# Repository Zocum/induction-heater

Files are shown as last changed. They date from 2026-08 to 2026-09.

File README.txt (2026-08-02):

# Induction Heater Controller
**STM32 Blue Pill (STM32F103C8T6) — Phase-Locked Resonance Tracking**

> ### ⚠️ Use V3 instead — see `V3/README.md`
>
> **V3 is the recommended version for any new build.** This document describes
> the older single-sketch firmware in `V1/`, kept for reference and for
> existing hardware.
>
> The reason to move is safety, not features. In this version the entire PLL
> runs in `loop()` while TIM1 generates the gate drive in hardware — so if
> `loop()` ever blocks, **the bridge keeps switching unsupervised**: no
> resonance tracking, the run timer never expires, and the PWM enable and lock
> switches stop being polled, so the front panel goes dead while the tank is
> still being driven.
>
> V3 closes that hole with a TIM4 dead-man supervisor that gracefully detunes
> and cuts the gate drive within ~200 ms, an IWDG watchdog behind it, and
> safe-boot arming inhibit after a reset. It also adds external gate-drive
> clamps and an EMI glitch filter on all digital inputs.
>
> V3 needs two hardware provisions this version does not (10 kΩ pull-downs on
> the gate driver inputs, and the GDT clamp transistors on PB8/PB9). The
> migration steps are in `V3/README.md`.
>
> If you stay on this version, at minimum keep the run timer short and never
> leave the heater unattended.

A firmware controller for a ZVS-style induction heater that automatically tracks the resonant frequency of the LC tank circuit using phase-locked loop (PLL) control. Runs on the STM32F103C8T6 ("Blue Pill") board using the Arduino STM32 framework.

---

## Features

- **Automatic resonance tracking** via a proportional phase-locked loop
- **Complementary gate drive** — TIM1 CH1/CH1N pair with hardware dead time (BDTR DTG)
- **Scheduled dead time** — floors at the shoot-through minimum at resonance, ramps up as you operate above it
- **Hardware input capture** — zero-software-latency phase measurement using TIM2 slaved to TIM1
- **Phase-target compensation** — dead time and signal-path delay are converted to degrees at the live frequency, so one `TARGET_PHASE` holds across coil swaps
- **Noise rejection** — ignores zero-crossing edges near PWM reload and compare events
- **Graceful exits** — soft stop, timer expiry and manual unlock all detune off resonance first, then cut the gates
- **PWM enable switch** — gate drive stays off at power-up until deliberately armed
- **Run timer on a pot** — 0-5 min, followed live, adjustable mid-run
- **Relay output** tied to the PWM state
- **DS18B20 temperature sensing** — raw 1-Wire bit-bang, no library dependency
- **SH1106 128x64 OLED display** — live frequency, phase, temperature, error, uptime, timer, and lock status
- **I2C bus guard** — health check, frame skip and bus recovery so a wedged display cannot stall the control loop
- **Physical controls** — lock switch, frequency UP/DOWN buttons with hold-to-repeat acceleration
- **Flash-optimised** — direct TIM1/TIM2 register access, no HardwareTimer abstraction

---

## Hardware

### Microcontroller
- STM32F103C8T6 ("Blue Pill"), 72 MHz

### Pin Map

| Pin | Function |
|-----|---|
| PA8 | PWM output -> gate driver (TIM1 CH1) |
| PB13 | Complementary PWM output -> gate driver (TIM1 CH1N) |
| PA0 | Tank current zero-crossing via LM339 (TIM2 CH1 input capture) |
| PA1 | DS18B20 temperature sensor (1-Wire) |
| PA2 | Run-timer setpoint pot wiper (analog) |
| PB0 | Relay driver (follows PWM state) |
| PB1 | PWM enable switch (active HIGH) |
| PB6 | I2C1 SCL -> OLED |
| PB7 | I2C1 SDA -> OLED |
| PB12 | Lock switch (active HIGH) |
| PB14 | Frequency UP button (active HIGH) |
| PB15 | Frequency DOWN button (active HIGH) |

> **PB12 conflict:** PB12 is also TIM1_BKIN. If you wire a hardware overcurrent
> trip into the break input, move the lock switch to a free pin (PB5/PB8/PB9) first.

### Additional Components
- **LM339 comparator** on CT output for clean zero-crossing detection
- **4.7 kOhm pull-up** resistor on PA1 to 3.3 V (DS18B20)
- **SH1106 128x64 OLED** on I2C address (default)
- Current transformer on tank circuit, burden resistor to GND
- **Two GDTs**, primaries driven differentially from the CH1/CH1N pair. The second is wired reversed so leg B runs 180 degrees anti-phase off the same pair and inherits the same dead band — one pair protects both half-bridges.
- **Relay module** on PB0. Set `RELAY_ACTIVE_LOW` to match: 1 for a typical opto-isolated board (LOW = energized), 0 for a low-side transistor driver.
- **Potentiometer** to 3.3 V / GND, wiper to PA2

---

## Dependencies

| Library | Purpose |
|---|---|
| `Wire` | I2C for OLED |
| `U8x8lib` (`U8g2`) | OLED driver (SH1106, HW I2C) |

No OneWire or DallasTemperature library required — DS18B20 is bit-banged manually.

---

## How It Works

### Frequency Generation
TIM1 is configured in PWM mode directly via registers, running at 72 MHz with no prescaler. The output frequency is:

```
f = 72,000,000 / (ARR + 1)
```

CCR1 is always set to half of ARR+1, giving a 50% duty cycle. Frequency is updated live by writing new ARR/CCR1 values under a brief interrupt lock.

Output is a **complementary pair** — CH1 (PA8) and CH1N (PB13) — with dead time inserted in hardware by the BDTR DTG field. During the dead-time window both pins go LOW, the GDT primary sits at 0 V, and that leg's gates are off.

### Dead Time
Dead time is scheduled rather than fixed. It floors at `DT_FLOOR_NS` (800 ns) at resonance and under lock, and ramps toward `DT_MAX_NS` (1500 ns) at `DT_SLOPE_NS_PER_KHZ` (100 ns/kHz) as the drive moves above resonance, slew-limited to `DT_SLEW_NS` (40 ns) per scheduler tick. The floor is the **shoot-through minimum and is never crossed**.

The default 800 ns floor is derived for an FF200R12KS4 at Tvj = 125 C, 200 A, +/-15 V, Rg = 4.7 ohm: td(off) + tf - td(on) = 480 ns delay race, plus tail current and GDT/driver skew and margin. **Verify on your own hardware** — scope gate-off until collector current (tail included) reaches zero, hot, at your actual Rg.

Set `DT_SCHEDULE_ENABLE` to 0 for a fixed `DT_FLOOR_NS` with no schedule.

### Phase Measurement (Hardware Input Capture)
Phase is measured entirely in hardware with zero software latency:

- **TIM1** generates the PWM on PA8 and emits an Update trigger (TRGO) on each reload (every PWM rising edge).
- **TIM2** runs at 72 MHz, slaved to TIM1 via ITR0 in Reset Mode — `TIM2->CNT` is reset to 0 at every PWM rising edge.
- **TIM2 CH1** (PA0) is configured as input capture, rising edge. `TIM2->CCR1` is latched in hardware the instant PA0 goes high.

The captured value directly encodes the phase offset:

```
phase (degrees) = (TIM2->CCR1 / (TIM1->ARR + 1)) x 360
```

Software/ISR latency is effectively zero. The residual delays are the LM339 comparator propagation delay plus CT conditioning (together `SIG_DELAY_NS`, default 1560 ns) and the gate dead time, which offsets the real CH1 edge from the TRGO reference the phase is measured against. The CC1IF flag is polled in the main loop at ~200 Hz rather than using interrupts.

### Phase Target Compensation
Both residual delays are **fixed-time**, so their contribution in degrees grows with frequency. The firmware converts them at the live frequency and references them to the point at which `TARGET_PHASE` was tuned:

```
phase_target_eff = TARGET_PHASE
                 + dtPhaseDeg(dead_time_ns + SIG_DELAY_NS, cur_freq)
                 - dtPhaseDeg(DT_TUNE_NS   + SIG_DELAY_NS, F_TUNE_HZ)
```

This is what lets a single `TARGET_PHASE` hold the same *actual* tank phase across coil swaps and load pull, and keeps the lock point from drifting as the dead-time schedule moves. `DT_TUNE_NS` (800 ns) and `F_TUNE_HZ` (40500 Hz) must describe the conditions you tuned `TARGET_PHASE` under.

### PLL Control
The control loop runs at ~200 Hz. It is **proportional-only** — frequency is the time-integral of phase, so a single gain on the phase error already drives the steady-state error to zero, with no I or D term needed.

| Constant | Default | Role |
|---|---|---|
| `LOCK_K` | 5.0 | Hz of correction per degree of phase error |
| `MAX_STEP` | 50.0 | Max frequency change per update (Hz) — stops a stray sample yanking the drive |
| `LOCK_DEADBAND` | 2.0 | Degrees; inside this the frequency is held, killing idle dither |
| `FREQ_UPD_INT` | 20 | ms between corrections (captures arrive ~4x faster) |
| `PH_N` | 15 | Depth of the moving-average phase filter |

The phase-vs-frequency slope is steepest near resonance, so the closer `TARGET_PHASE` is tuned toward Fres, the gentler `LOCK_K` has to be — too hot and it limit-cycles around target.

**Acquisition** always begins `ACQ_OFFSET` (12 kHz) **above** the resonance estimate and walks down, so the loop always approaches from the stable, inductive side. Seeding from wherever the knob is parked is what let earlier versions run away. `locked_freq` is only trusted once the loop is genuinely parked inside the deadband.

A filtered phase jump greater than `PHASE_JUMP_TH` (120 degrees) means the drive fell through resonance to the capacitive side. This forces an unlock and a jump back above resonance, reported as `!JUMP` on serial.

### Noise Rejection
Zero-crossing edges arriving within `1/NOISE_DIV` (1/20 = 5%) of either the PWM reload point or the compare event are discarded. If more than `REJECT_SWEEP_TH` (15) consecutive edges are rejected, the frequency is swept upward at 15 Hz/tick to escape the dead zone.

### I2C Bus Guard
Every OLED write is a blocking transfer, and the PLL, the run timer and the switch polling all live in the same `loop()`. A display wedged by an EMI burst would therefore stall the control loop while TIM1 kept the bridge switching. Before each frame the firmware checks both I2C lines are idle-high; if not it skips the frame and, at most every 500 ms, recovers the bus (9 SCL pulses, manual STOP, controller re-init). The `s` command reports `i2crec` / `i2cskip` so a marginal bus is visible before it becomes a failure.

The bus runs at 100 kHz rather than the 400 kHz default for noise margin. See `HARDWARE.md` in the V3 project for the hardware-side hardening checklist.

---

## Frequency Range

| Parameter | Constant | Value |
|---|---|---|
| Minimum frequency | `MIN_FREQ` | 1 kHz |
| Maximum frequency | `MAX_FREQ` | 100 kHz |
| Step size | `FREQ_STEP` | 100 Hz |
| Default start | `start_frequency` | 46 kHz |
| Unlocked offset | `UNLOCK_OFFSET` | +4000 Hz above start |
| Acquisition offset | `ACQ_OFFSET` | +12000 Hz above resonance estimate |
| Unlock / timer backoff | `UNLOCK_BACKOFF` / `TIMER_BACKOFF` | 7000 Hz |
| Soft-stop backoff | `PWM_SOFTSTOP_OFFSET` | 7000 Hz |
| Backoff ramp rate | `FREQ_RAMP_HZ_PER_MS` | 7.0 Hz/ms (~7 kHz in 1 s) |

---

## Controls

Two switches gate the bridge, and both matter:

- **PWM enable (PB1)** — master. PWM does *not* run at power-up; the gate drivers are held at 0 V until this is flipped HIGH. This lets you power the bridge and charge the DC link first, then start switching. Turning it off while locked performs a soft stop: ramp `PWM_SOFTSTOP_OFFSET` up off resonance over ~1 s, *then* cut the gates. Not locked, the gates cut immediately.
- **Lock (PB12)** — engages closed-loop tracking and arms the run timer. With PWM on and lock off, the bridge free-runs at the current manual frequency.

The **pot (PA2)** sets the run time, 0-5 min (`TIMER_MAX_S`, with a `TIMER_MIN_S` = 10 s floor). It is followed live, so the duration can be changed mid-run — turn it up for more time, or down toward zero to end the run now. Below `TIMER_OFF_FRAC` (2%) the timer is disabled and lock runs indefinitely. On expiry the drive parks `TIMER_BACKOFF` above resonance and unlocks, but **PWM stays on and the relay stays energized**; re-lock to run again. Reported as `!TIMER` on serial.

Calibrate the pot ends with `POT_RAW_LO` / `POT_RAW_HI`: read the raw counts at each knob extreme from the `s` command (`pot=`), then set these slightly *inside* the measured values so 0 and full scale are easy to reach.

---

## Display Layout (OLED)

```
Induction Heater
Relay: ON         <- follows PWM state
L: 46.25kHz       <- L = locked, F = free/manual
T:  68C           <- DS18B20 temperature, "--" if absent
P: 23.1 E: 0.3    <- live phase + error (error shown when locked)
Time 03:42        <- uptime
Run -02:15        <- timer: "Run -mm:ss" / "Set mm:ss" / "Timer done" / "Timer off"
** LOCKED **      <- or "Tracking..." / "PWM ON" / "PWM OFF"
```

Row 4 shows the live phase whenever a valid capture exists, regardless of lock state, so you can watch phase change while sweeping manually; the `E:` error field appears only when locked. Row 7 shows `PWM OFF` whenever the enable switch is down, which takes precedence over the lock state.

---

## Calibration

Do this on the bench with the **tank unpowered** and the gate drive scoped. Dead time first — the phase target depends on it.

**1. Dead time.** Scope gate-off until collector current (tail current included) reaches zero, hot, at your actual Rg and Vge(off). Set `DT_FLOOR_NS` to that plus margin, and set `DT_TUNE_NS` to the dead time you are about to tune the phase target at. At startup the schedule is printed to serial:

```
DT floor=800ns max=1500ns tune=800ns DTGfloor=0x3A
```

**2. Phase target.** `TARGET_PHASE` is the measured phase at true resonance — mostly the LM339 propagation delay and CT conditioning, plus the dead-time offset.

1. Enable debug output (`v` via serial).
2. Manually sweep frequency using the UP/DOWN buttons until resonance is found.
3. Note the phase reading at true resonance.
4. Set `TARGET_PHASE` to that value.
5. Set `F_TUNE_HZ` to the frequency you tuned at, and `SIG_DELAY_NS` to your measured signal-path delay. **Measure this one** — the in-code comment describes a 250 ns two-coil fit (42 deg @ 77.5 kHz, 22 deg @ 24.5 kHz) but the constant actually ships at 1560 ns, so the comment and the value disagree.
6. Recompile and flash.

At startup, the target phase is printed to serial:
```
Target phase=-122.0deg
```

Retune after **any** change to the dead time. The `s` command reports both the raw target (`tgt=`) and the compensated one in use (`eff=`).

**3. Pot ends.** Read raw counts at both knob extremes from `s` (`pot=`), then set `POT_RAW_LO` / `POT_RAW_HI` just inside those values.

---

## Serial Commands

| Command | Action |
|---|---|
| `f+` | Increase start frequency by one step |
| `f-` | Decrease start frequency by one step |
| `s` | Status line: frequency, lock, `pwm=`, `pot=`, `set=`, `tgt=`, `eff=`, `dt=`, `i2crec=`, `i2cskip=` |
| `v` | Toggle verbose debug output (phase data every 100 ms) |

The firmware also emits unsolicited `!JUMP` (resonance crossing detected) and `!TIMER` (run timer expired).

---

## Building & Flashing

This project targets the **Arduino STM32** (STM32duino) framework.

1. Install [STM32duino](https://github.com/stm32duino/Arduino_Core_STM32) board package in Arduino IDE.
2. Install **U8g2** library (for `U8x8lib.h`).
3. Select board: **Generic STM32F1 series -> BluePill F103C8**.
4. Upload method: STLink or serial bootloader.
5. Compile and flash.

Builds to roughly 35 KB of flash and 1.8 KB of RAM, comfortably inside the C8's nominal 64 KB.

---

## Safety Notes

> Induction heaters operate at high voltages and currents. The LC tank can develop dangerous voltages even from low supply rails, and the DC link stays charged after power-down. Ensure proper isolation, enclosure, and never operate without adequate knowledge of high-frequency power electronics.

- **This version has no loop supervision.** The PLL runs in `loop()` while TIM1 generates gate drive in hardware, so any blocking fault in `loop()` leaves the bridge switching with the front panel unresponsive. The I2C guard closes the one known cause; it does not make the loop supervised. V3 adds a TIM4 dead-man and an IWDG watchdog — see `V3/README.md`.
- `DT_FLOOR_NS` is a **shoot-through floor**. Verify it against your own devices before applying bus voltage; the default is derived for one specific IGBT.
- The firmware does not implement over-temperature shutdown by itself — the DS18B20 is instrumentation only. Add hardware protection.
- Always verify gate driver signals, including the dead band, with an oscilloscope before connecting the full power stage.
- The PWM enable switch is the master arm and the lock switch enables closed-loop control; ensure the heater is in a safe state before flipping either.
- Add 10 kOhm pull-downs on the gate driver inputs so they read a hard OFF while the MCU pins float during reset.

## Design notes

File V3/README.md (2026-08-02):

# Induction Heater Controller — V3

**STM32 Blue Pill (STM32F103C8T6) — phase-locked resonance tracking for a
full-bridge ZVS induction heater.**

V3 is a ground-up restructure of the single-sketch V1 firmware into a modular
PlatformIO project, built around one change of principle: **the PLL runs in
`loop()`, so `loop()` is a safety-critical path and is now supervised in
hardware.** Everything else follows from that.

> ⚠️ This firmware drives a mains-fed full bridge into a resonant tank. Read
> [Safety](#safety) before powering anything. The `TARGET_PHASE_DEG` and
> `DT_FLOOR_NS` constants **must** be retuned for your hardware — the shipped
> values are for one specific build.

---

## What's new since V1

| | V1 (`uC_logic.ino`) | V3 |
|---|---|---|
| Structure | one 1058-line `.ino` | 6 modules, `src/` + `include/`, central `config.h` |
| Build | Arduino IDE | PlatformIO (`bluepill_f103c8_128k`) |
| Loop freeze | **bridge keeps switching, unsupervised** | TIM4 dead-man → graceful detune → MOE cut → IWDG reset |
| Watchdog | none | IWDG, ~800 ms, with safe-boot arming inhibit |
| Gate drive | TIM1 MOE only | + external GDT input clamps (`GDT_EN`/`GDT_NEN`) |
| Digital inputs | raw `digitalRead()` | `stable_read()` EMI glitch filter on all four |
| I2C failure | blocks `loop()` | health check, frame skip, bounded bus recovery |
| Restart | immediate | `RESTART_LOCKOUT_MS` cooldown for bleeder discharge |

If you are running V1, see [MIGRATING](#migrating-from-v1) — the pin map grew
and V3 needs two new hardware provisions.

---

## Layout

```
platformio.ini      board, framework, U8g2 dependency
include/config.h    ALL tunables — pins, frequencies, gains, safety timings
src/main.cpp        module wiring + UI (buttons, switches, pot, serial)
src/bridge.cpp      TIM1 PWM/dead-time/MOE, TIM2 capture, relay, GDT clamps
src/pll.cpp         acquisition, phase tracker, backoff ramps
src/safety.cpp      TIM4 supervisor + IWDG
src/oled.cpp        SH1106 driver with I2C bus guard
src/ds18b20.cpp     bit-banged 1-Wire (no library)
HARDWARE.md         I2C/EMI hardening checklist + bench validation procedure
```

Tune the machine in `config.h`. You should rarely need to touch anything else.

---

## Hardware

### Pin map

| Pin | Function |
|-----|---|
| PA8 | PWM out → gate driver (TIM1_CH1) |
| PB13 | Complementary PWM out (TIM1_CH1N) |
| PA0 | Tank current zero-crossing from LM339 (TIM2_CH1 capture) |
| PA1 | DS18B20 (4.7 kΩ pull-up to 3.3 V) |
| PA2 | Run-timer setpoint pot wiper (analog) |
| PB0 | Relay driver (follows PWM state) |
| PB1 | PWM enable switch (active HIGH) |
| PB12 | Lock switch (active HIGH) — *also TIM1_BKIN, see note* |
| PB14 / PB15 | Frequency UP / DOWN buttons |
| PB6 / PB7 | I2C1 SCL / SDA → SH1106 OLED |
| **PB8** | **GDT_EN — gate-drive clamp release (new in V3)** |
| **PB9** | **GDT_NEN — inverted clamp enable (new in V3)** |

> **PB12 conflict:** PB12 is TIM1_BKIN. If you ever wire a hardware overcurrent
> trip into the break input, move the lock switch to PB5/PB8/PB9 first.

### Required external provisions

1. **10 kΩ pull-downs on both MIC4421/4422 driver inputs.** During an IWDG
   reset the MCU pins float for a few ms. OSSI drives the outputs low whenever
   the timer is alive, but the reset window itself needs the resistors.
2. **GDT clamp transistors** on `GDT_EN`/`GDT_NEN`, with a 10 k pull-down on EN
   and 10 k pull-up on /EN so the safe (clamped) state holds through reset
   before firmware takes over.

`HARDWARE.md` covers the I2C/EMI hardening — pull-up stiffening, series
resistors, cable twisting — in priority order.

---

## How it works

### Frequency and dead time

TIM1 generates a complementary pair on PA8/PB13 at `f = 72 MHz / (ARR+1)`,
50 % duty, with **hardware dead time** from the BDTR DTG field. Both GDT
primaries are driven differentially; the second is wired reversed, so one pair
protects both half-bridges.

Dead time is *scheduled*, not fixed: it floors at `DT_FLOOR_NS` (800 ns — the
shoot-through minimum, never crossed) at resonance and ramps toward
`DT_MAX_NS` as you operate above resonance, at `DT_SLOPE_NS_PER_KHZ`. The
phase target is compensated for the live dead time and for the fixed
`SIG_DELAY_NS` signal-path delay, so **one** `TARGET_PHASE_DEG` holds the same
actual tank phase across coil swaps and load pull.

### Phase measurement

Zero software latency. TIM1's update event drives TRGO → TIM2 ITR0 in reset
mode, so `TIM2->CNT` clears on every PWM rising edge; TIM2_CH1 latches `CCR1`
the instant PA0 goes high:

```
phase (deg) = (TIM2->CCR1 / (TIM1->ARR + 1)) × 360
```

`CC1IF` is polled at ~200 Hz. Edges landing within `1/NOISE_DIV` of the reload
or compare event are discarded as noise.

### Control

Proportional-only. Frequency is the time-integral of phase, so a single gain
on the phase error already drives steady-state error to zero — no I or D term.
`LOCK_K` sets aggressiveness, `MAX_STEP` caps the per-update jump, and
`LOCK_DEADBAND` silences idle dither.

Acquisition always **starts `ACQ_OFFSET` above** the resonance estimate and
walks down, clearing the unstable near-resonance band. Overshoot the lock point
and the measured angle wraps, and the loop runs away to `MAX_FREQ`.

Every graceful exit — soft stop, timer expiry, manual unlock — uses a
non-blocking ramp at `FREQ_RAMP_HZ_PER_MS` to detune *first*, then cuts the
gates. This preserves ZVS on the way out and avoids ringing the input filter.

---

## Safety

Three layers, in the order they act:

**Layer 1 — TIM4 dead-man, ~200 ms.** `loop()` feeds a heartbeat. If it goes
stale for `SAFETY_STALL_MS` while PWM is enabled, a 1 kHz ISR takes over and
performs the *same* graceful detune as a normal soft stop — ramping up
`SAFETY_RAMP_HZ_TICK` per ms to `PWM_SOFTSTOP_OFFSET` above the stall
frequency, settling, then cutting MOE and latching `SAFETY_FAULT`.

**Layer 2 — IWDG, ~800 ms.** LSI-clocked, survives anything short of power
loss. Fed only from the main loop, with one deliberate exception: the Layer-1
ISR keeps feeding it *while ramping* so a reset can't fire mid-detune. Once MOE
is cut, feeding stops.

**Layer 3 — I2C bus guard.** `oled.cpp` checks both lines are idle-high before
every transaction, skips the frame if not, and attempts bounded bus recovery
(9 clock pulses + manual STOP + re-init). This is what stops a wedged display
from invoking layers 1–2 in the first place.

**After a watchdog reset** the firmware boots into a safe state and *refuses to
arm PWM* until the enable switch has been cycled through OFF. Row 7 shows
`WDT rst-sw off`.

A latched `SAFETY_FAULT` clears only by cycling the PWM switch low.

---

## Building

Needs [PlatformIO](https://platformio.org/). The U8g2 dependency is fetched
automatically.

```bash
pio run              # build
pio run -t upload    # flash via ST-Link
pio device monitor   # 115200 baud
```

Board is `bluepill_f103c8_128k` — the C8 is built as the 128 k CB part because
the firmware overflows the nominal C8 flash size. Serial is USART1
(PA9 TX / PA10 RX); uncomment the CDC block in `platformio.ini` for USB serial.

---

## Operating

Two switches gate the bridge, and both matter:

- **PWM enable (PB1)** — master. PWM does *not* run at power-up. Bring up the
  bus and charge the DC link first, then flip this. Turning it off performs a
  soft stop (detune, then gate cut).
- **Lock (PB12)** — engages closed-loop tracking and arms the run timer. With
  PWM on and lock off, the bridge runs open-loop at the manual frequency.

The **pot (PA2)** sets run time, 0–5 min, followed live. Below
`TIMER_OFF_FRAC` the timer is disabled and lock runs indefinitely. On expiry
the drive parks `TIMER_BACKOFF` above resonance with PWM still on.

### Display

```
Induction Heater
Relay: ON            follows PWM state
L: 43.25kHz          L = locked, F = free/manual
T:  68C              DS18B20, "--" if absent
P: 23.1 E: 0.3       live phase + error (error shown when locked)
Time 03:42           uptime
Run -02:15           timer: Run/Set/Timer done/Timer off
** LOCKED **         safety state dominates this row
```

### Serial commands (115200)

| Cmd | Action |
|---|---|
| `f+` / `f-` | Nudge frequency one `FREQ_STEP` |
| `s` | Status: freq, lock, pwm, gdt, pot, phase target, dead time, safety state, `i2crec`/`i2cskip` |
| `v` | Toggle verbose phase debug (100 ms) |
| `x` | **Deliberately freeze the loop** to validate the safety chain. Refused while PWM is enabled. |

---

## Calibration

Do this on the bench with the **tank unpowered** and the gate drive scoped.

1. **Dead time.** Scope gate-off to collector current (tail included) at your
   actual Rg and Vge(off), hot. Set `DT_FLOOR_NS` to that plus margin. The
   shipped 800 ns is for an FF200R12KS4 at 125 °C, 200 A, ±15 V, Rg = 4.7 Ω.
2. **Phase target.** Enable debug (`v`), sweep manually with the UP/DOWN
   buttons to find resonance, note the phase, and set `TARGET_PHASE_DEG`.
   Set `DT_TUNE_NS` to the dead time you tuned at.
3. **Pot ends.** Read raw counts at both knob extremes via `s` (`pot=`), then
   set `POT_RAW_LO`/`POT_RAW_HI` slightly *inside* those values.
4. **Validate the safety chain** — full procedure in `HARDWARE.md`.

---

## Migrating from V1

1. Add the two hardware provisions above (driver pull-downs, GDT clamps). The
   watchdog is not safe to run without them.
2. Carry your tuned constants across into `config.h`: `TARGET_PHASE_DEG`
   (V1 `TARGET_PHASE`), `DT_FLOOR_NS`, `DT_TUNE_NS`, `SIG_DELAY_NS`,
   `F_TUNE_HZ`, `POT_RAW_LO`/`HI`, `START_FREQUENCY`.
3. Note `ACQ_OFFSET` changed from 12000 to 6000 Hz, and `START_FREQUENCY` from
   46000 to 43000 — check both against your coil.
4. Flash, then run the bench validation in `HARDWARE.md` *before* connecting
   the power stage.

---

## Safety notes

Induction heaters operate at high voltages and currents. The LC tank develops
dangerous voltages even from low supply rails, and the DC link stays charged
after power-down.

- Always verify gate drive on a scope before connecting the power stage.
- The firmware has **no over-temperature shutdown**. The DS18B20 is
  instrumentation only — add hardware thermal protection.
- The supervisor protects against *firmware* stalls. It is not a substitute for
  a hardware overcurrent trip into TIM1_BKIN.
- Never operate without adequate knowledge of high-frequency power electronics.

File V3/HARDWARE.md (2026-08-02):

# OLED / I2C hardware hardening checklist

Goal: cut the rate of corrupted I2C transactions so the firmware's recovery
layer (oled.cpp) almost never has to act. Ordered by payoff.

## At the STM32 end

1. **Stiffen the pull-ups.** Replace or parallel the module's typical 10k down
   to **2.2k (or 1.5k) to 3.3 V**, placed at the STM32 side of the cable. Noise
   margin on an open-drain bus is set by how hard the line is held high. At
   100 kHz (firmware now forces this clock) 1.5k is comfortably in spec.
2. **33-100 ohm series resistor** in BOTH SDA and SCL, right at the MCU pins.
   Damps ringing and limits transient current injected into PB6/PB7.

## At the OLED end

3. **47-100 pF to GND** on each line at the display module. With the series R
   this forms an RC that rounds off coupled spikes. Do NOT go larger - I2C
   edges must stay clean (400 pF total bus budget).
4. **Ferrite bead in series with the OLED VCC**, plus **100 nF + 4.7 uF**
   directly at the module. Many "I2C glitches" are really supply dips on the
   display coinciding with an EMI event.

## The cable

5. **Keep it under ~10 cm** if at all possible.
6. **Twist SDA with GND, and SCL with VCC** (two twisted pairs). Never twist
   SDA with SCL - that maximizes crosstalk and manufactures phantom
   start/stop conditions.
7. If the run must be longer: **shielded cable**, shield bonded to STM32
   ground with a short fat connection (no long pigtail). Route it away from
   the tank leads and GDT wiring; cross power runs at 90 degrees.

## Structural options (if it still misbehaves)

8. **Switch the SH1106 module to 4-wire SPI** if it exposes the mode strap
   (many do via a jumper resistor). Push-pull lines, no bidirectional wire,
   no bus-hang state: a corrupted byte becomes one garbage frame instead of a
   wedge. This is the real cure; the firmware's oled.cpp would then shrink to
   a plain driver.
9. Alternatively an **I2C buffer (P82B96 / PCA9600)** at the MCU end for
   strong drive across the cable.

# Watchdog-related hardware (required for the new firmware)

10. **10k pull-downs on the MIC4421/4422 inputs** (both drivers). During an
    IWDG reset the MCU pins float for a few ms; the pull-downs guarantee the
    gate drivers read a hard OFF instead of noise. With OSSI the outputs are
    driven low whenever the timer is alive, but the reset window itself needs
    the resistors.

# Bench validation procedure (tank UNPOWERED, gate drive scoped)

1. Flash, open serial monitor.
2. Enable PWM at low bus voltage / no bus.
3. Send `x` (deliberate loop freeze). Expected sequence on the scope/serial:
   - ~200 ms: supervisor takeover, frequency ramps up ~7 kHz over ~700 ms
   - MOE cut (gate drive dies cleanly at the detuned frequency)
   - ~0.8 s later: IWDG reset, banner shows "!WDT RESET - safe boot"
   - Display row 7 shows "WDT rst - sw off"; PWM refuses to arm until the
     enable switch has been cycled through OFF.
4. Unplug SDA mid-run: display freezes but buttons/frequency control stay
   live; `s` shows i2cskip incrementing. Replug: i2crec increments once and
   the display comes back within ~500 ms. No freeze, no fault.

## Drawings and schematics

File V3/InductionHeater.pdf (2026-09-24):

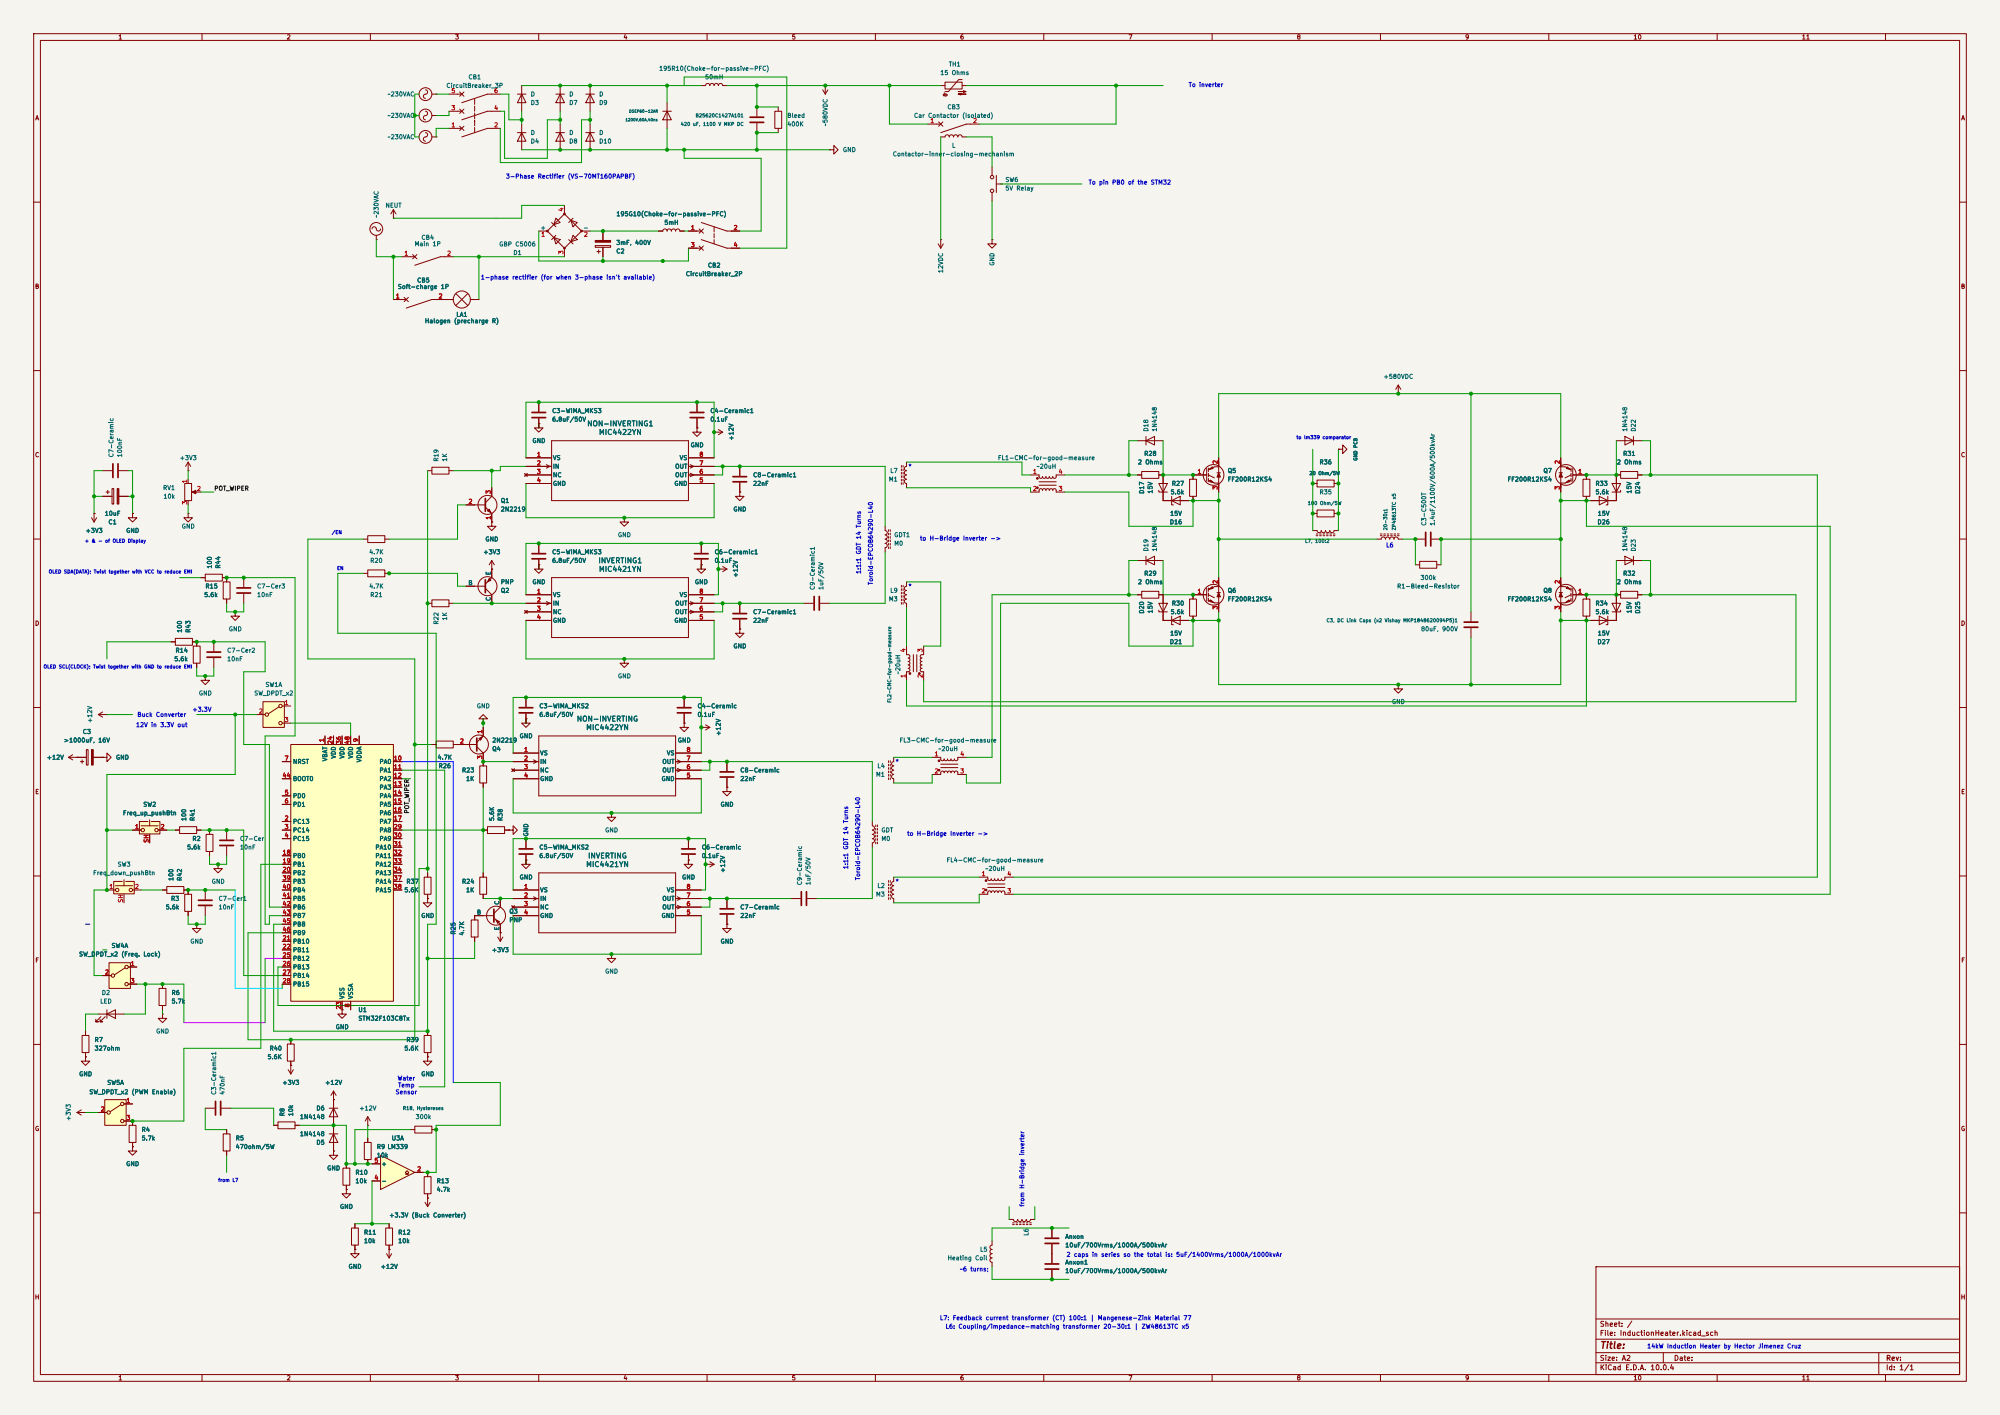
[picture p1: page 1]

195R10(Choke-for-passive-PFC) 50mH

To inverter To pin PB0 of the STM32

Contactor-inner-closing-mechanism

195G10(Choke-for-passive-PFC) 5mH
0.1uF CB2 CircuitBreaker_2P

FL1-CMC-for-good-measure

C3, DC Link Caps (x2 Vishay MKP1848620094P5)1

3 FL2-CMC-for-good-measure ~20uH

FL3-CMC-for-good-measure

L7: Feedback current transformer (CT) 100:1 | Mangenese-Zink Material 77 1:1:1 GDT 14 Turns

FL4-CMC-for-good-measure

2 caps in series so the total is: 5uF/1400Vrms/1000A/1000kvAr L6: Coupling/impedance-matching transformer 20-30:1 | ZW48613TC x5

14kW Induction Heater by Hector Jimenez Cruz

Size: A2 | Rev:
KiCad E.D.A. 10.0.4 | Id: 1/1

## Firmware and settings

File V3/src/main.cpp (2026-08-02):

#include "config.h"
#include "bridge.h"
#include "pll.h"
#include "safety.h"
#include "oled.h"
#include "ds18b20.h"

// ===================================================================
// main: wiring between modules + all UI (buttons, switches, pot, serial).
//
// Loop structure (order matters):
//   serial -> safety feed -> temp -> ramp -> BUTTONS/SWITCHES -> timer
//   -> PLL control -> debug -> DISPLAY LAST.
// Inputs are polled before the display so the slowest, most EMI-fragile
// peripheral can never add latency to the safety-relevant controls.
//
// ALL four digital inputs (BTN_UP/BTN_DOWN/LOCK/PWM_EN) go through the
// stable_read() EMI glitch filter: a state change is accepted only after
// the raw pin has held the new level for STABLE_MS continuously. This is
// what stops switch-node dV/dt bursts above ~40 V bus from "pressing"
// buttons through the weak internal pull-downs.
// ===================================================================

// ---- temperature ----
static int16_t currentTempX10 = 0;
static unsigned long lastTempRead = 0;
static bool tempSensorFound = false;
static bool tempConvStarted = false;

// ---- run timer ----
static uint32_t timer_setpoint_s = 0;
static uint32_t pot_set_s = 0;
static bool timer_running = false;
static bool timer_fired = false;
static unsigned long timer_start_ms = 0;

// ---- UI state ----
static unsigned long prog_start = 0;
static unsigned long last_up = 0, last_down = 0;
static unsigned long up_press_start = 0, down_press_start = 0;
static bool up_was_pressed = false, down_was_pressed = false;
static bool last_lock = false, last_pwm = false;
static bool wdt_arm_inhibit = false;    // set on WDT boot until switch seen LOW
static bool pwm_pending = false;

// ---- debug ----
static bool debug_phase = true;
static unsigned long last_debug = 0;
extern volatile uint16_t dbg_cnt_val;
extern volatile bool     dbg_rejected;
extern volatile uint16_t dbg_rej_cnt;

// ===================================================================
// EMI glitch filter: a state change is accepted only after the raw pin
// has held the new level continuously for STABLE_MS. Real presses are
// >50 ms; switching-edge EMI bursts are ns-us. Latency cost: 30 ms,
// imperceptible on a human control.
#define STABLE_MS 30
typedef struct { bool stable; bool raw; unsigned long t; } debounced_t;

static bool stable_read(debounced_t *d, uint32_t pin) {
  bool r = digitalRead(pin);
  if (r != d->raw) { d->raw = r; d->t = millis(); }
  else if (r != d->stable && (millis() - d->t) >= STABLE_MS) d->stable = r;
  return d->stable;
}

static debounced_t db_up, db_dn, db_lock, db_pwm;

// ===================================================================

static uint32_t readTimerPot(void) {
  uint32_t acc = 0;
  for (int i = 0; i < 16; i++) acc += analogRead(POT_PIN);
  int raw = (int)(acc / 16);
  float f = (float)(raw - POT_RAW_LO) / (float)(POT_RAW_HI - POT_RAW_LO);
  if (f < 0.0f) f = 0.0f;
  if (f > 1.0f) f = 1.0f;
  if (f < TIMER_OFF_FRAC) return 0;
  uint32_t s = (uint32_t)(f * (float)TIMER_MAX_S + 0.5f);
  if (s < TIMER_MIN_S) s = TIMER_MIN_S;
  if (s > TIMER_MAX_S) s = TIMER_MAX_S;
  return s;
}

static void armTimer(void) {
  timer_setpoint_s = readTimerPot();
  timer_fired = false;
  if (timer_setpoint_s > 0) { timer_running = true; timer_start_ms = millis(); }
  else timer_running = false;
}

static void readTemp(void) {
  if (millis() - lastTempRead < 1500) return;
  lastTempRead = millis();
  if (!tempSensorFound) return;
  if (tempConvStarted) {
    int16_t t10 = (int16_t)((ds_read_temp_raw() * 10) / 16);
    if (t10 > -500 && t10 < 1500) currentTempX10 = t10;
  }
  ds_start_conv();
  tempConvStarted = true;
}

static void handleSerial(void) {
  static char cb[12];
  static uint8_t cp = 0;

  while (Serial.available()) {
    char c = Serial.read();
    if (c == '\n' || c == '\r') {
      if (cp == 0) continue;
      cb[cp] = '\0'; cp = 0;

      if (cb[0] == 'f' || cb[0] == 'F') {
        pll_manual_step(cb[1] == '+');
      }
      else if (cb[0] == 's') {
        Serial.print(cur_freq); Serial.print(F(" "));
        Serial.print(phase_locked ? '1' : '0');
        Serial.print(F(" pwm="));  Serial.print(pwm_enabled ? '1' : '0');
        Serial.print(F(" gdt="));  Serial.print(gdt_is_enabled() ? '1' : '0');
        Serial.print(F(" pot="));  Serial.print(analogRead(POT_PIN));
        Serial.print(F(" set="));  Serial.print(pot_set_s);
        Serial.print(F(" tgt="));  Serial.print(TARGET_PHASE_DEG, 1);
        Serial.print(F(" eff="));  Serial.print(phase_target_eff, 1);
        Serial.print(F(" dt="));   Serial.print(dead_time_ns);
        Serial.print(F(" saf="));  Serial.print((int)safety_state());
        Serial.print(F(" i2crec=")); Serial.print(oled_recover_count());
        Serial.print(F(" i2cskip=")); Serial.println(oled_skip_count());
      }
      else if (cb[0] == 'v') {
        debug_phase = !debug_phase;
        Serial.print(F("Debug:")); Serial.println(debug_phase ? F("ON") : F("OFF"));
      }
      else if (cb[0] == 'x') {
        // DELIBERATE FREEZE - validates the safety chain (ISR detune ~200ms,
        // MOE cut, IWDG reset ~0.8s, safe boot). Refused while the bridge is
        // switching: serial RX is an EMI-exposed line and this command must
        // never be triggerable by noise during a real run. Test with the
        // drive disabled (supervisor arms on pwm_enabled anyway, so validate
        // by enabling PWM with the TANK UNPOWERED, then sending 'x' - the
        // refusal below only blocks the case where the bridge is live).
        if (pwm_enabled) {
          Serial.println(F("!FREEZE refused: PWM is enabled"));
        } else {
          Serial.println(F("!FREEZE test - blocking loop now"));
          Serial.flush();
          for (;;) { /* heartbeat starves; supervisor takes over */ }
        }
      }
    } else if (cp < sizeof(cb) - 1) cb[cp++] = c;
  }
}

// ===================================================================

void setup() {
  Serial.begin(115200);
  delay(300);

  Serial.print(F("Target phase=")); Serial.print(TARGET_PHASE_DEG, 1); Serial.println(F("deg"));
  Serial.print(F("DT floor=")); Serial.print(DT_FLOOR_NS);
  Serial.print(F("ns max="));   Serial.print(DT_MAX_NS);
  Serial.print(F("ns tune="));  Serial.println(DT_TUNE_NS);

  prog_start = millis();

  oled_init();
  oled_splash("Init...");

  tempSensorFound = ds_reset();
  if (tempSensorFound) {
    ds_start_conv();
    delay(750);
    currentTempX10 = (int16_t)((ds_read_temp_raw() * 10) / 16);
    tempConvStarted = true;
  }
  delay(200);

  pinMode(LOCK_PIN,   INPUT_PULLDOWN);
  pinMode(TANK_PIN,   INPUT);
  pinMode(BTN_UP,     INPUT_PULLDOWN);
  pinMode(BTN_DOWN,   INPUT_PULLDOWN);
  pinMode(PWM_EN_PIN, INPUT_PULLDOWN);

  analogReadResolution(12);
  pinMode(POT_PIN, INPUT_ANALOG);

  // Relay off before the pin becomes an output (no active-low glitch).
  #if RELAY_ACTIVE_LOW
    digitalWrite(RELAY_PIN, HIGH);
  #else
    digitalWrite(RELAY_PIN, LOW);
  #endif
  pinMode(RELAY_PIN, OUTPUT);
  #if RELAY_ACTIVE_LOW
    digitalWrite(RELAY_PIN, HIGH);
  #else
    digitalWrite(RELAY_PIN, LOW);
  #endif

  // GDT clamps: safe state (EN=LOW clamped, NEN=HIGH) driven BEFORE the pins
  // become outputs and before any TIM1 config below - same no-glitch pattern
  // as the relay. Takes over seamlessly from the external pulls that held
  // this exact state through reset.
  digitalWrite(GDT_EN_PIN,  LOW);
  digitalWrite(GDT_NEN_PIN, HIGH);
  pinMode(GDT_EN_PIN,  OUTPUT);
  pinMode(GDT_NEN_PIN, OUTPUT);
  digitalWrite(GDT_EN_PIN,  LOW);
  digitalWrite(GDT_NEN_PIN, HIGH);

  // Seed the glitch filters from the real pin states so a switch already in
  // a position at boot doesn't produce a phantom edge 30 ms in. wdt_arm_inhibit
  // still guards the PWM switch after a watchdog reset.
  db_up.raw   = db_up.stable   = digitalRead(BTN_UP);     db_up.t   = millis();
  db_dn.raw   = db_dn.stable   = digitalRead(BTN_DOWN);   db_dn.t   = millis();
  db_lock.raw = db_lock.stable = digitalRead(LOCK_PIN);   db_lock.t = millis();
  db_pwm.raw  = db_pwm.stable  = digitalRead(PWM_EN_PIN); db_pwm.t  = millis();
  last_lock = db_lock.stable;
  last_pwm  = false;   // an already-HIGH PWM switch at boot must still produce
                       // one deliberate edge to arm (matches old behavior)

  bridge_init(start_frequency + UNLOCK_OFFSET);
  capture_init();
  pll_reset_state();
  bridge_update_dt_schedule(start_frequency);

  // Safety LAST, after everything is in a defined state. If the previous
  // reset was an IWDG reset, inhibit arming until the switch is seen LOW.
  safety_init();
  if (safety_wdt_boot()) {
    wdt_arm_inhibit = true;
    Serial.println(F("!WDT RESET - safe boot, cycle PWM switch to arm"));
  }

  oled_clear();
}

// ===================================================================

void loop() {
  handleSerial();

  // Feed both protection layers once per healthy pass.
  safety_heartbeat();
  safety_iwdg_kick();

  readTemp();
  pll_ramp_task();

  // --- ALL digital inputs through the EMI glitch filter ---
  bool lsw = stable_read(&db_lock, LOCK_PIN);
  bool psw = stable_read(&db_pwm,  PWM_EN_PIN);

  // WDT-boot arming inhibit clears once the switch has been seen safe/LOW.
  if (wdt_arm_inhibit && !psw) wdt_arm_inhibit = false;

  // Latched supervisor fault: bookkeeping (ISR already cut MOE + relay),
  // clears only via switch LOW.
  if (safety_state() == SAFETY_FAULT) {
    timer_running = false;
    if (!psw) { safety_clear_fault(); last_pwm = false; }
  }

  // --- BTN_UP / BTN_DOWN (polled BEFORE any display work) ---
  bool up_now = stable_read(&db_up, BTN_UP);
  if (up_now && !up_was_pressed) { up_press_start = millis(); up_was_pressed = true; }
  if (!up_now) up_was_pressed = false;
  if (up_now) {
    unsigned long hold = millis() - up_press_start;
    unsigned long rep = (hold > 6000) ? 40 : (hold > 3000) ? 70 : DEBOUNCE_MS;
    if (millis() - last_up > rep) { last_up = millis(); pll_manual_step(true); }
  }

  bool dn_now = stable_read(&db_dn, BTN_DOWN);
  if (dn_now && !down_was_pressed) { down_press_start = millis(); down_was_pressed = true; }
  if (!dn_now) down_was_pressed = false;
  if (dn_now) {
    unsigned long hold = millis() - down_press_start;
    unsigned long rep = (hold > 6000) ? 40 : (hold > 3000) ? 70 : DEBOUNCE_MS;
    if (millis() - last_down > rep) { last_down = millis(); pll_manual_step(false); }
  }

  // --- Lock switch ---
  if (lsw != last_lock) {
    last_lock = lsw;
    if (lsw) {
      pll_engage();
      if (pwm_enabled && !timer_running) armTimer();
    } else {
      timer_running = false; timer_fired = false;
      pll_release_manual();
    }
  }

  // --- PWM enable switch ---
  if (psw != last_pwm) {
    last_pwm = psw;
    if (psw) {
      if (safety_state() != SAFETY_OK || wdt_arm_inhibit) {
        // refuse; display shows why
      } else if (!bridge_restart_ready()) {
        pwm_pending = true;          // arm when cooldown expires
      } else {
        pll_cancel_ramp();
        if (lsw) { pll_engage(); bridge_pwm_enable(); armTimer(); }
        else     { phase_locked = false; bridge_pwm_enable(); }
      }
    } else {
      pwm_pending = false;
      timer_running = false; timer_fired = false;
      pll_softstop();
    }
  }

  // --- Run timer: follow the pot live ---
  static unsigned long last_pot_ms = 0;
  if (millis() - last_pot_ms > 150) {
    last_pot_ms = millis();
    pot_set_s = readTimerPot();
    if (timer_running) timer_setpoint_s = pot_set_s;
  }

  if (timer_running && pwm_enabled &&
      (millis() - timer_start_ms >= timer_setpoint_s * 1000UL)) {
    if (phase_locked) {
      pll_timer_expired();
      last_lock = lsw;               // suppress auto re-lock while switch held
    }
    timer_running = false;
    timer_fired = true;
    Serial.println(F("!TIMER"));
  }

  // --- PLL control (200 Hz internally) ---
  pll_control_task(lsw);

  if (pwm_pending && psw && bridge_restart_ready() &&
      safety_state() == SAFETY_OK && !wdt_arm_inhibit) {
    pwm_pending = false;
    pll_cancel_ramp();
    if (lsw) { pll_engage(); bridge_pwm_enable(); armTimer(); }
    else     { phase_locked = false; bridge_pwm_enable(); }
  }

  // --- Debug ---
  if (debug_phase && phase_locked && (millis() - last_debug > 100)) {
    last_debug = millis();
    uint32_t arr1 = TIM1->ARR + 1;
    float deg = ((float)dbg_cnt_val / (float)arr1) * 360.0f;
    Serial.print(cur_freq);   Serial.print(' ');
    Serial.print(dbg_cnt_val); Serial.print(' ');
    Serial.print(deg, 1);
    Serial.print(dbg_rejected ? F(" nope ") : F("  ok "));
    Serial.print(dbg_rej_cnt);
    Serial.print(F(" tgt=")); Serial.println(phase_target_eff, 1);
  }

  // --- Display LAST (guarded, throttled, skippable) ---
  disp_data_t d;
  d.err = pll_disp_err;       d.in_db = pll_in_db;
  d.timer_running = timer_running; d.timer_fired = timer_fired;
  d.timer_setpoint_s = timer_setpoint_s; d.timer_start_ms = timer_start_ms;
  d.pot_set_s = pot_set_s;
  d.temp_x10 = currentTempX10; d.temp_ok = tempSensorFound;
  d.prog_start_ms = prog_start;
  oled_task(&d);

  delay(1);
}

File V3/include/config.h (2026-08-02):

#ifndef IH_CONFIG_H
#define IH_CONFIG_H

#include <Arduino.h>

// ===================================================================
// Induction Heater Controller - central configuration
// Target: STM32F103CB "Blue Pill" (build as 128k part)
// ===================================================================

// ===== PINS =====
#define PWM_PIN      PA8    // TIM1_CH1
#define CH1N_PIN     PB13   // TIM1_CH1N
#define TANK_PIN     PA0    // TIM2_CH1 input capture (LM339 zero-cross)
#define LOCK_PIN     PB12   // lock switch (active HIGH). NOTE: also TIM1_BKIN.
#define BTN_UP       PB14
#define BTN_DOWN     PB15
#define DS_PIN       PA1    // DS18B20
#define RELAY_PIN    PB0
#define PWM_EN_PIN   PB1    // PWM enable switch, active HIGH
#define POT_PIN      PA2    // run-timer pot wiper
#define OLED_SCL_PIN PB6    // I2C1 SCL (twist together with GND to reduce EMI)
#define OLED_SDA_PIN PB7    // I2C1 SDA (twist together with VCC to reduce EMI)

// GDT input clamps: external transistors that force both MIC4421/4422 inputs
// low (driver outputs 0 V, GDT primaries parked, blocking caps discharging)
// whenever GDT_EN is LOW / GDT_NEN is HIGH. That is the safe state: default
// at boot and after every PWM shutdown. GDT_NEN is always driven as the
// complement of GDT_EN. External pulls (10k down on EN, 10k up on /EN) hold
// the safe state while the MCU pins float during reset; firmware only has to
// init the pins to the safe state and sequence the transitions.
// PB8/PB9: TIM4_CH3/CH4 unused (safety supervisor uses only the update IRQ),
// I2C1 is NOT remapped (runs on PB6/PB7), CAN unused. 5V-tolerant.
#define GDT_EN_PIN   PB8    // HIGH = clamps released, PWM passes to drivers
#define GDT_NEN_PIN  PB9    // inverted enable, complement of GDT_EN

// ===== RELAY POLARITY =====
#define RELAY_ACTIVE_LOW 1

// ===== FREQUENCY =====
#define TCLK_HZ         72000000UL
#define FREQ_STEP       100UL
#define MIN_FREQ        1000UL
#define MAX_FREQ        100000UL
#define START_FREQUENCY 43000UL
#define UNLOCK_OFFSET   4000UL
#define ACQ_OFFSET      6000UL   // acquisition seed: resonance est. + this, walk DOWN
#define UNLOCK_BACKOFF  7000UL
#define TIMER_BACKOFF   7000UL
#define RESTART_LOCKOUT_MS  3000u  // min off-time before re-arm (~6x bleeder tau)

// ===== SOFT STOP / RAMP =====
#define PWM_SOFTSTOP_OFFSET  7000UL   // Hz above resonance before cutting drive
#define FREQ_RAMP_HZ_PER_MS  7.0f     // ~7 kHz in 1 s

// ===== DEAD TIME (FF200R12KS4 schedule) =====
#define DT_FLOOR_NS          800u     // shoot-through floor - NEVER crossed
#define DT_MAX_NS            1500u
#define DT_SLOPE_NS_PER_KHZ  100.0f
#define DT_SLEW_NS           40u
#define DT_SCHEDULE_ENABLE   1
#define DT_TUNE_NS           800u

// ===== PHASE =====
#define TARGET_PHASE_DEG  (-122.0f)   // retune per hardware
#define SIG_DELAY_NS      1560u
#define F_TUNE_HZ         40500u
#define PHASE_JUMP_TH     120.0f
#define PH_N              15          // phase history depth

// ===== CONTROL LOOP =====
#define LOCK_K            5.0f        // Hz per degree
#define MAX_STEP          50.0f       // Hz per update
#define LOCK_DEADBAND     2.0f        // deg
#define FREQ_UPD_INT_MS   20UL
#define REJECT_SWEEP_TH   15
#define NOISE_DIV         20UL

// ===== RUN TIMER =====
#define TIMER_MAX_S       300UL
#define TIMER_MIN_S       10UL
#define TIMER_OFF_FRAC    0.02f
#define POT_RAW_LO        30
#define POT_RAW_HI        4100

// ===== UI =====
#define DEBOUNCE_MS       200UL
#define DISPLAY_PERIOD_MS 250UL

// ===== SAFETY (new) =====
// Main-loop heartbeat supervisor (runs in TIM4 ISR at 1 kHz):
#define SAFETY_STALL_MS      200u   // loop silent this long + PWM on -> takeover
#define SAFETY_RAMP_HZ_TICK  10u    // Hz per 1 ms tick during ISR detune (~700 ms)
#define SAFETY_SETTLE_MS     5u     // dwell at detuned freq before MOE cut
// Independent watchdog (LSI ~40 kHz):
#define IWDG_TIMEOUT_MS      800u   // hardware reset backstop
// I2C guard:
#define I2C_RECOVER_MIN_MS   500u   // min spacing between bus recovery attempts
#define I2C_CLOCK_HZ         100000u

#endif

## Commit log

2026-08-02 V1: move sketch to V1/, guard I2C bus, correct stale README
    [uC_logic.ino]
2026-08-02 Fix layout: move V3 to repo root, restore missing V1 sketch
    [bridge.cpp, config.h, ds18b20.cpp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]
2026-08-05 add schematic
    [InductionHeater.kicad_sch]
2026-08-25 Add PDF export of V3 schematic
    Plotted from InductionHeater.kicad_sch with kicad-cli 10.0.4
    (sch export pdf) so the schematic is viewable without KiCad.
2026-09-17 V3 schematic: add passive PFC choke and bulk cap, refresh PDF
    Schematic changes:
    - Add 5mH choke 195G10 for passive PFC
    - Add C2, 3mF bulk electrolytic
    - Fix reference typo on the existing choke:
    195R10(Choke-for-passive-PF) -> 195R10(Choke-for-passive-PFC)
    Re-plotted InductionHeater.pdf from the schematic with kicad-cli 10.0.4
    (sch export pdf) so the exported view matches the source again.
    [InductionHeater.kicad_sch]
2026-09-22 V3 schematic: fix GDT ratio label, mirror gate-drive symbols
    - Correct the gate drive transformer annotation from
    "1:1:1:1:1 GDT 14 Turns" to "1:1:1 GDT 14 Turns" (both instances)
    - Mirror six symbols in the gate-drive area (x = 157.48 / 168.91 /
    177.8), flipping their pin and property placement to match
    No components added or removed; netlist is unchanged.
    Re-plotted InductionHeater.pdf with kicad-cli 10.0.4 (sch export pdf).
    [InductionHeater.kicad_sch]
2026-09-23 V3 schematic: add run-timer pot, fix C2 placement, add soft-charge input
    - Add RV1 (10k) for the run-timer setpoint: ends on +3V3/GND, wiper
    to PA2 (U1 pin 12) via the POT_WIPER net label. Placed beside the
    OLED power hookup.
    - Move C2 (3mF) from series in the rectifier's negative leg to across
    the single-phase DC output, after the passive-PFC choke and before
    CB2, so it is isolated from the 580VDC bus when CB2 is open.
    - Add single-pole main breaker CB4 in the Line feed to the single-phase
    bridge, with a parallel soft-charge branch (CB5 + halogen lamp LA1)
    to precharge the capacitors before closing CB4.
    - Connect the bridge's second AC input (D1 pin 4) to NEUT; it was
    previous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
    [InductionHeater.kicad_sch]
2026-09-24 V3 schematic: move C2 directly across the single-phase bridge
    Place C2 (3mF) across D1's DC output, before the passive-PFC choke,
    matching the wiring drawn in the working KiCad project. The choke
    returns to its original position between D1(-) and CB2.
    Re-plotted InductionHeater.pdf with kicad-cli 10.0.4.
    [InductionHeater.kicad_sch]
